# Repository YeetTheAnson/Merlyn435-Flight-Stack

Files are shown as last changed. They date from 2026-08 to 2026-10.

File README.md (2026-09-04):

# Merlyn435 Flight Stack

## Introduction
This is my custom Merlyn435 Flight Stack! This project was made as a successor to my previous Merlyn411 flight controller due to several limitations. It lacked in its processing power and free UART ports. Its mounting pattern was also unconventional at 25mm, making its mounting incompatible with any ESCs on the market. By upgrading to the AT32F435@288MHz, the new Merlyn435 easily handles 8k8 PID loop and advanced autonomous flights with 3 spare UART ports.

The Merlyn435 also upgrades the IMU from the MPU6500 to the LSM6DSK320X, which provides significantly better vibration noise rejection at $3.8\ \mathrm{mdps}/\sqrt{\mathrm{Hz}}$ compared to $10\ \mathrm{mdps}/\sqrt{\mathrm{Hz}}$. This results in cooler motors and more stable flights with fewer gyro filters, preventing issues such as mid throttle oscillation and flyaways.

The Merlyn435 flight controller is designed for a wide battery voltage ranging from 2 to 6 cells. This flight controller can also be mounted in various sizes of drones from 2" to as big as it can get.

It is a 3 in 1 flight controller offers features such as an integrated 2.4GHz ExpressLRS receiver and an OSD to overlay telemetry directly in the video feed. Furthermore, it has 16MB of flash memory for blackbox logging to assist in flight tuning.

The MerlynESC is a 4 in 1 ESC which runs on Bluejay firmware and also operates from 2 to 6s battery voltages. Its maximum continuous current is 40A per motor and peaks up to 55A for a maximum duration of 10 seconds.

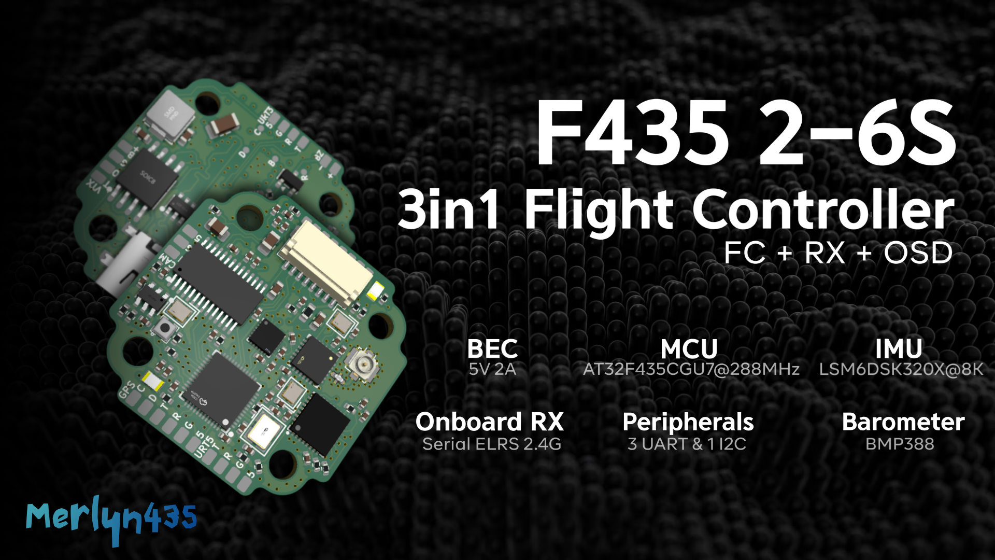
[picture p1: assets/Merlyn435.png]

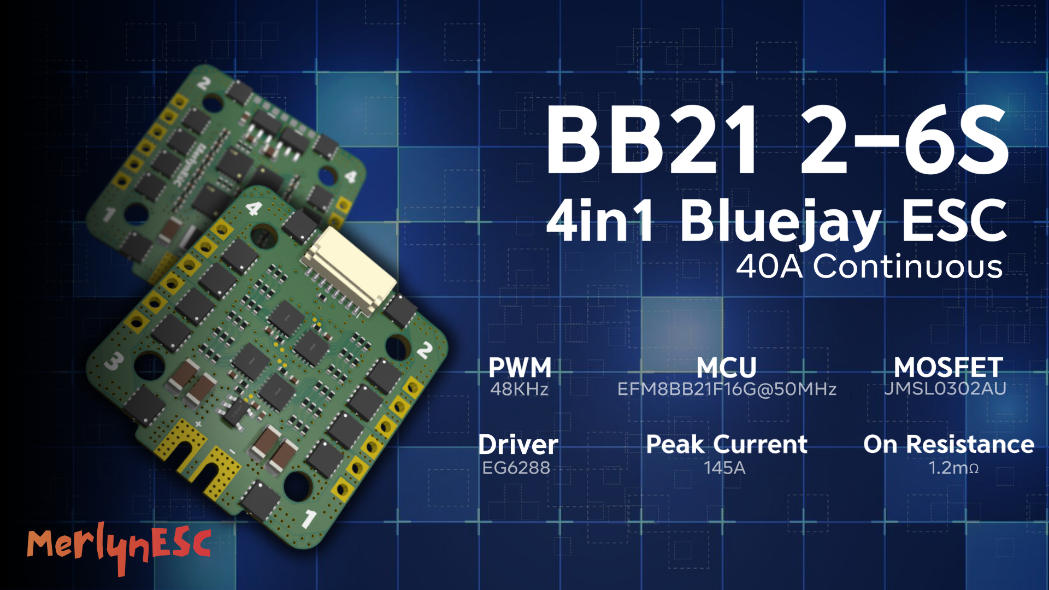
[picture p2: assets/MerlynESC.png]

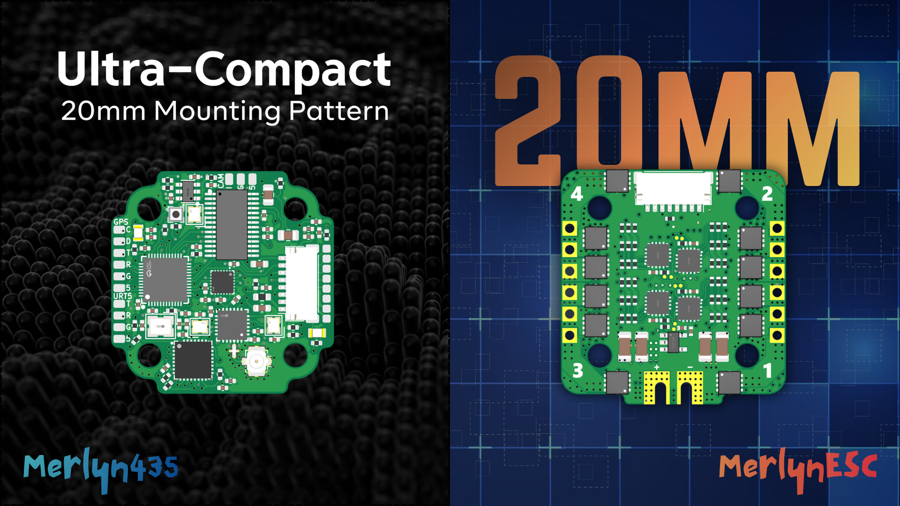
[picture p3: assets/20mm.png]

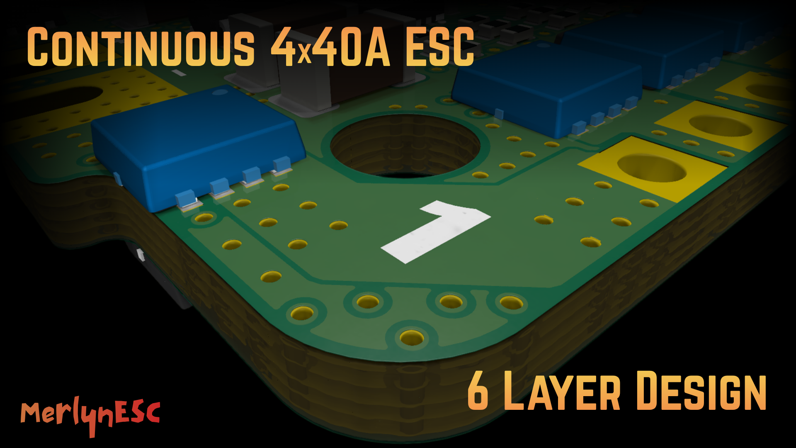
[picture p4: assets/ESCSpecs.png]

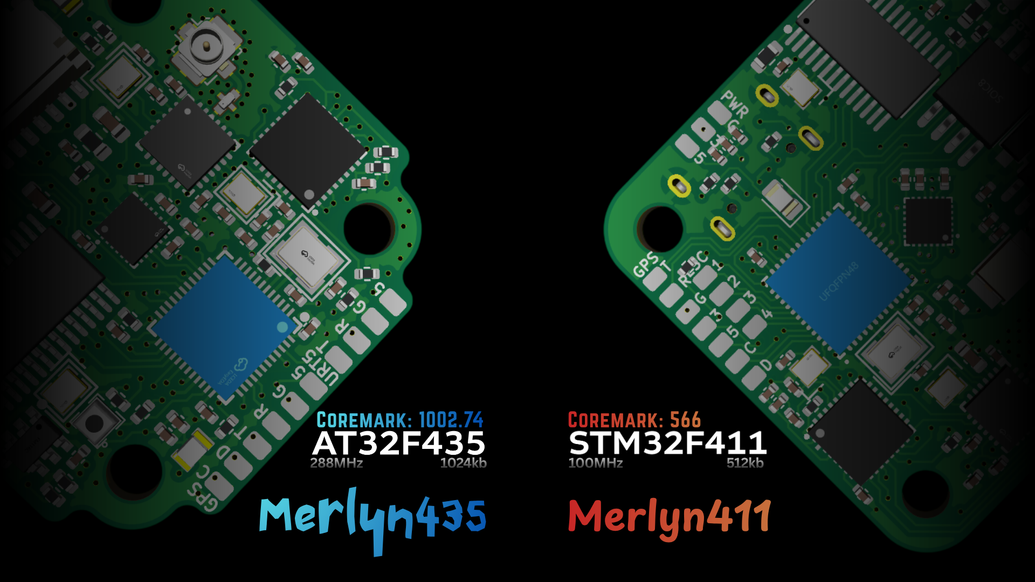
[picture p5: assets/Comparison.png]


| Feature | Merlyn435 | Merlyn411 |
|---|---|---|
| **MCU** | AT32F435CGU7 @ 288MHz | STM32F411CEU6 @ 100MHz |
| **MCU Flash Size** | 1024kB | 512kB |
| **UART Interfaces** | 5 Hardware UART (2 internal, 3 free) | 2 Hardware UART + 1 SoftSerial (1 internal, 1 softserial, 1 free) |
| **IMU** | LSM6DSK320X (SPI) | MPU6500 (SPI) |
| **Barometer** | BMP388 (I2C) | None |
| **OSD** | AT7456E (SPI) | AT7456E (SPI) |
| **Blackbox Flash** | 16MB (SPI) | 16MB (SPI) |
| **Integrated Receiver** | Serial ExpressLRS 2.4GHz  | Serial ExpressLRS 2.4GHz |
| **Mounting Size** | M2 20x20mm | M2 25.5x25.5mm |
| **BEC** | 5V 2A @ 1.1MHz Synchronous | 5V 2A @ 150kHz Asynchronous |
| **ESC Connection** | 8 pin JST-SH (Betaflight standard) | Direct solder pads |

## Hardware Specifications

### Merlyn435
* **MCU:** AT32F435CGU7
* **IMU:** LSM6DSK320X @ SPI1
* **Barometer:** BMP388 @ 0x76
* **OSD:** AT7456E @ SPI2
* **Blackbox:** W25Q128JV 16MB Flash @ SPI2
* **Receiver:** Serial ExpressLRS (ESP8285 + SX1281) @ UART2
* **Voltage range:** 2-6s LiPo / Li-ion / LiHV
* **Power Supply:** LMR51420YDDCR buck converter + SPX3819M5-L-3-3 LDO
* **Mounting:** M2 20x20mm

### MerlynESC
* **MCU:** EFM8BB21F16G
* **MOSFET:** JMSL0302AU
* **Gate Driver:** EG6288
* **Max Current:** 145A Peak / 40A Continuous @ 1.2mΩ
* **Voltage range:** 2-6s LiPo / Li-ion / LiHV
* **Power Supply:** HT75C0-1 12V LDO + HT7533-1 3.3V LDO
* **Mounting:** M2 20x20mm

## Pinout
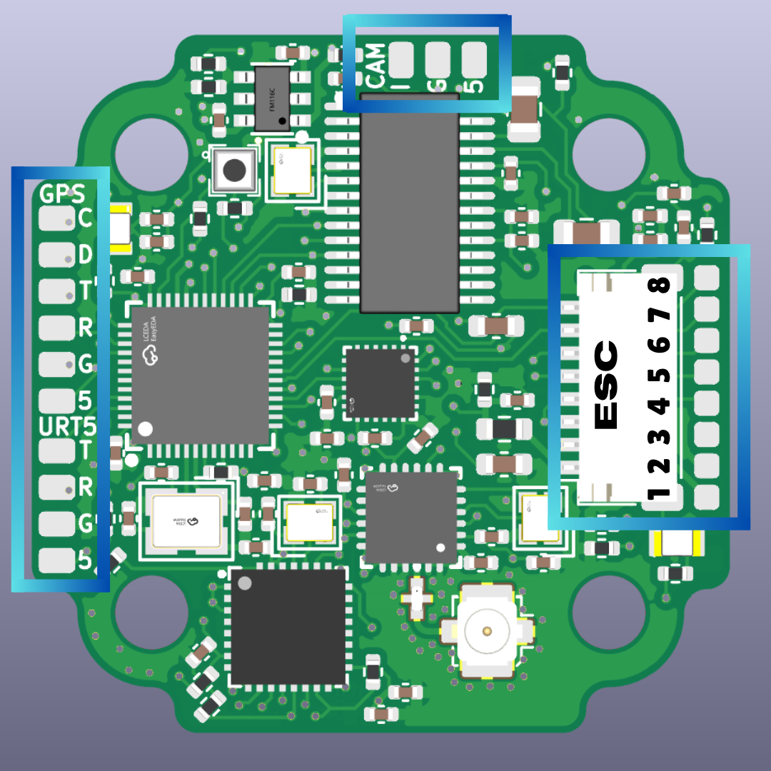
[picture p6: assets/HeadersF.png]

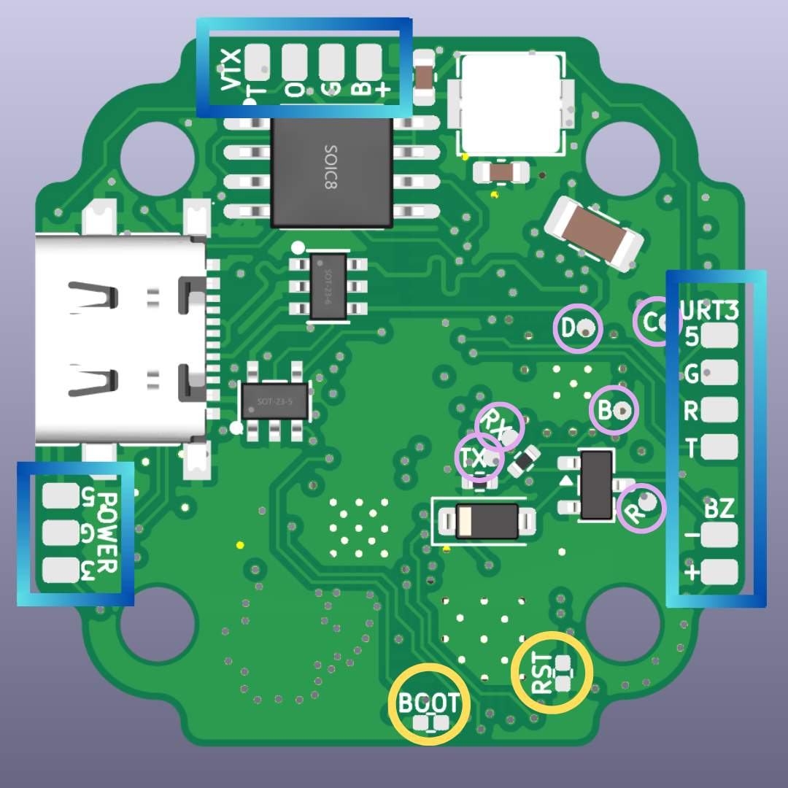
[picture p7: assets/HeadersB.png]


| Header | Pin name | AT32 Pin | Description |
|---|---|---|---|
| **ESC** | `(1)BAT+` | - | Battery Positive Input from ESC |
| | `(2)GND` | - | Ground |
| | `(3)NC` | - | No Connection |
| | `(4)CURR` | PA1 | Current Sense Input |
| | `(5)M1` | PB6 | Motor 1 Signal Output |
| | `(6)M2` | PB7 | Motor 2 Signal Output |
| | `(7)M3` | PB0 | Motor 3 Signal Output |
| | `(8)M4` | PB1 | Motor 4 Signal Output |
| **GPS** | `C` | PH2 | I2C SCL (Internal BMP388 & External Magnetometer) |
| | `D` | PH3 | I2C SDA (Internal BMP388 & External Magnetometer) |
| | `T` | PB4 | UART7 TX |
| | `R` | PB3 | UART7 RX |
| | `G` | - | Ground |
| | `5` | - | 5V Power Output |
| **URT5** | `T` | PB9 | UART5 TX |
| | `R` | PB8 | UART5 RX |
| | `G` | - | Ground |
| | `5` | - | 5V Power Output |
| **CAM** | `I` | - | Analog Video Input |
| | `G` | - | Ground |
| | `5` | - | 5V Power Output |
| **URT3** | `5` | - | 5V Power Output |
| | `G` | - | Ground |
| | `R` | PB11 | UART3 RX |
| | `T` | PB10 | UART3 TX |
| **VTX** | `T` | PA9 | UART1 TX (IRC Tramp / SmartAudio) |
| | `O` | - | Analog Video Output (OSD Overlay) |
| | `G` | - | Ground |
| | `B+` | - | Battery Output for VTX |
| **BZ** | `-` | PC15 | Beeper MOSFET  Pin |
| | `+` | - | 5V Power Output |
| **POWER** | `3` | - | 3.3V Power Input/Output |
| | G | - | Ground |
| | `5` | - | 5V Power Input/Output |
| **Test Points** | `RX` | PA2 | UART2 TX (ExpressLRS RX) |
| | `TX` | PA3 | UART2 RX (ExpressLRS TX) |
| | `D` | PA13 | SWDIO (Debug & Flash) |
| | `C` | PA14 | SWCLK (Debug & Flash) |
| | `R` | NRST | NRST (Debug & Flash) |
| | `B` | BOOT0 | BOOT0 (Debug & Flash) |
| **Jumpers** | `BOOT` | ESP8285 GPIO0 | Bridge to enter ExpressLRS bootloader mode |
| | `RST` | ESP8285 CHIP_EN | Bridge to disable internal ExpressLRS receiver |

----

## Hardware Overview

### Merlyn435
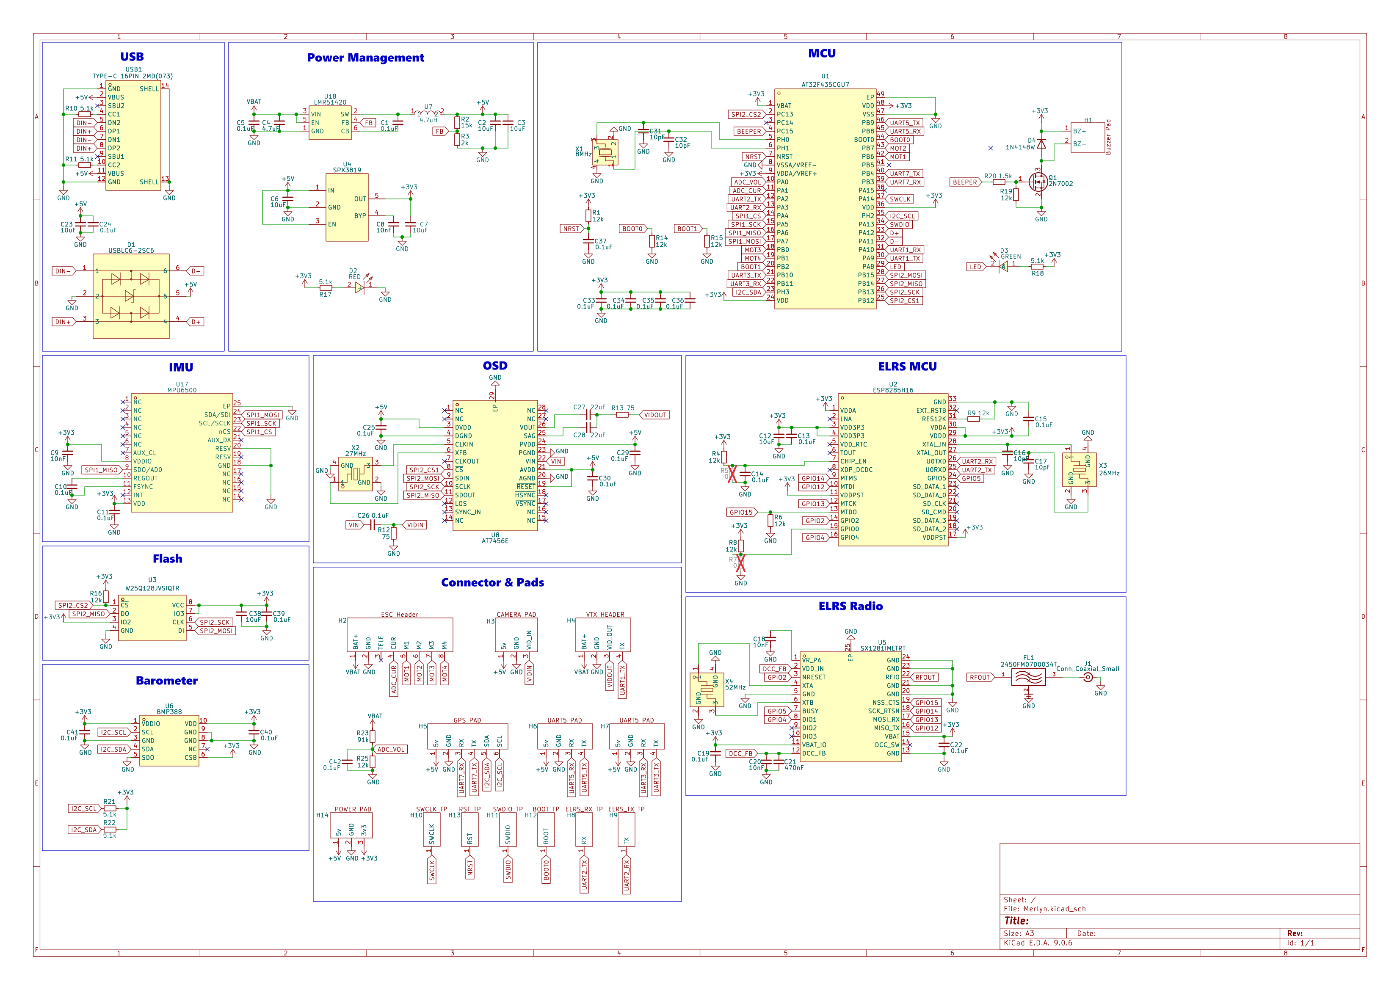
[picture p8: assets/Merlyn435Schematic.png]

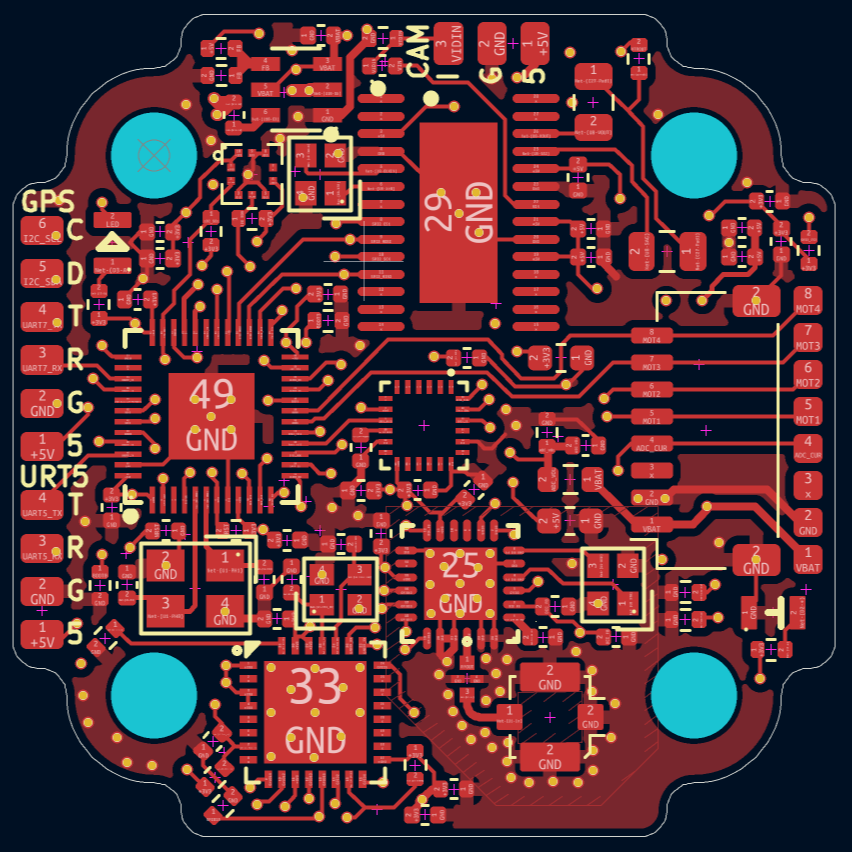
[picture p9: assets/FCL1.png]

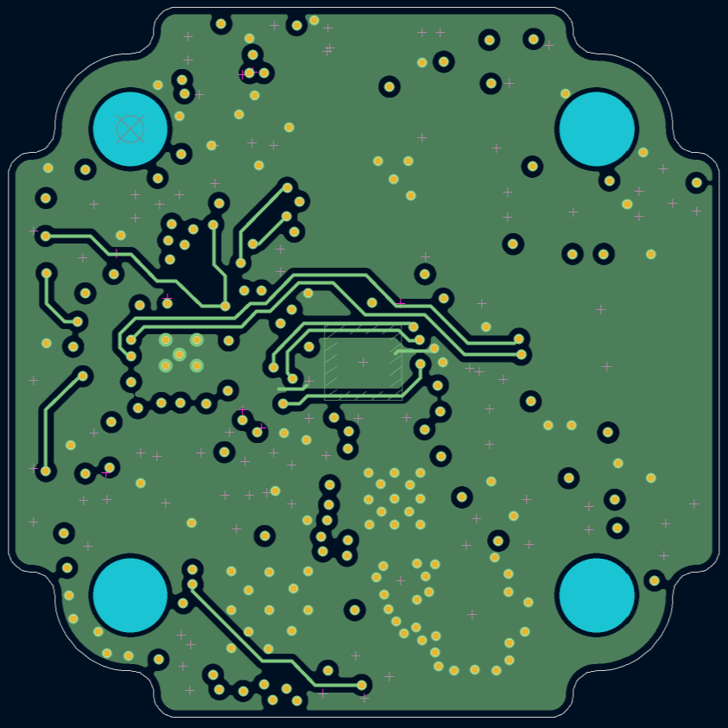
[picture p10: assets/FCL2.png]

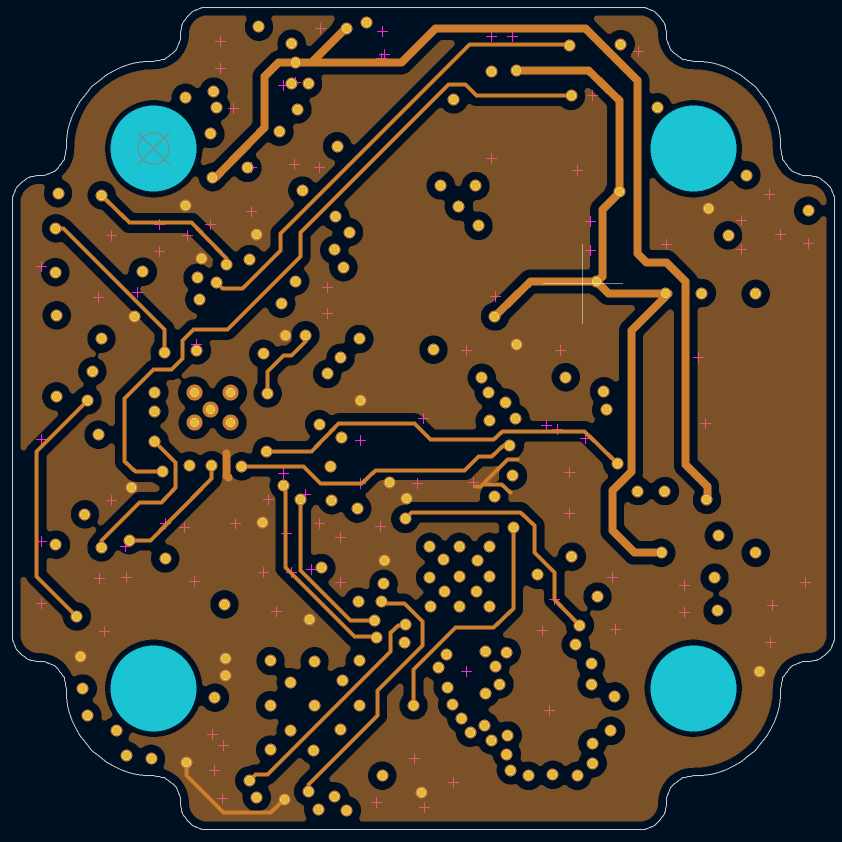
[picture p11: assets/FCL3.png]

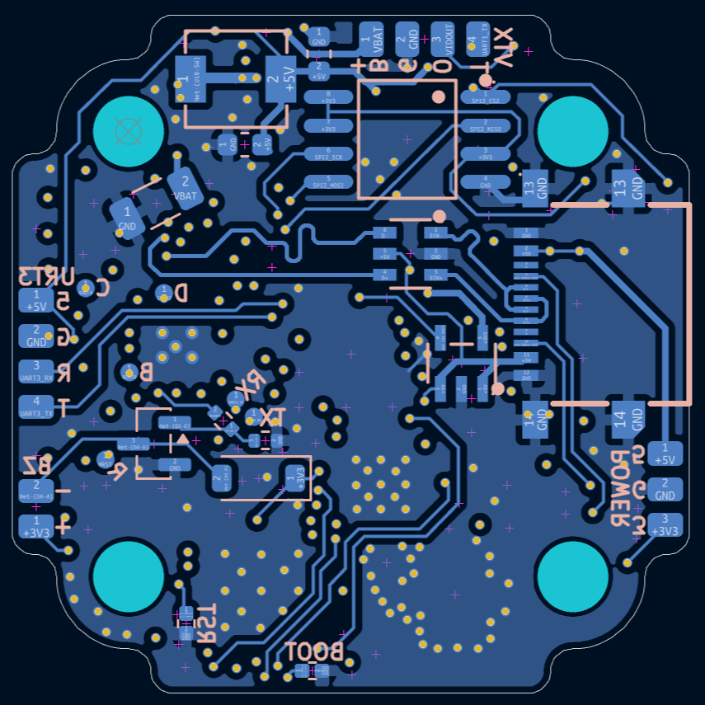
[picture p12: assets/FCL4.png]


### MerlynESC
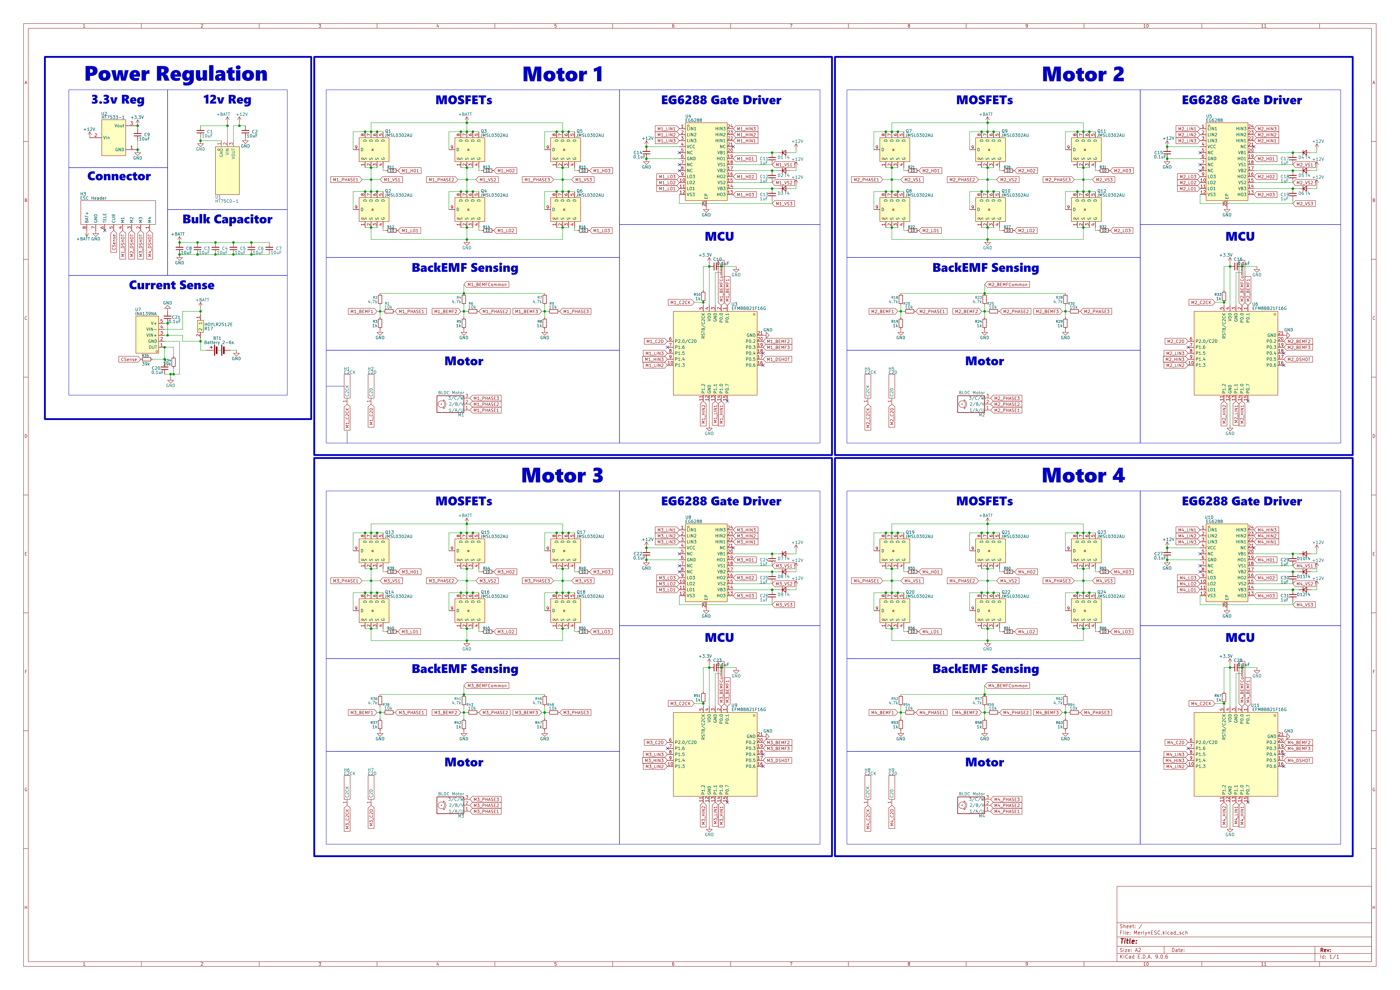
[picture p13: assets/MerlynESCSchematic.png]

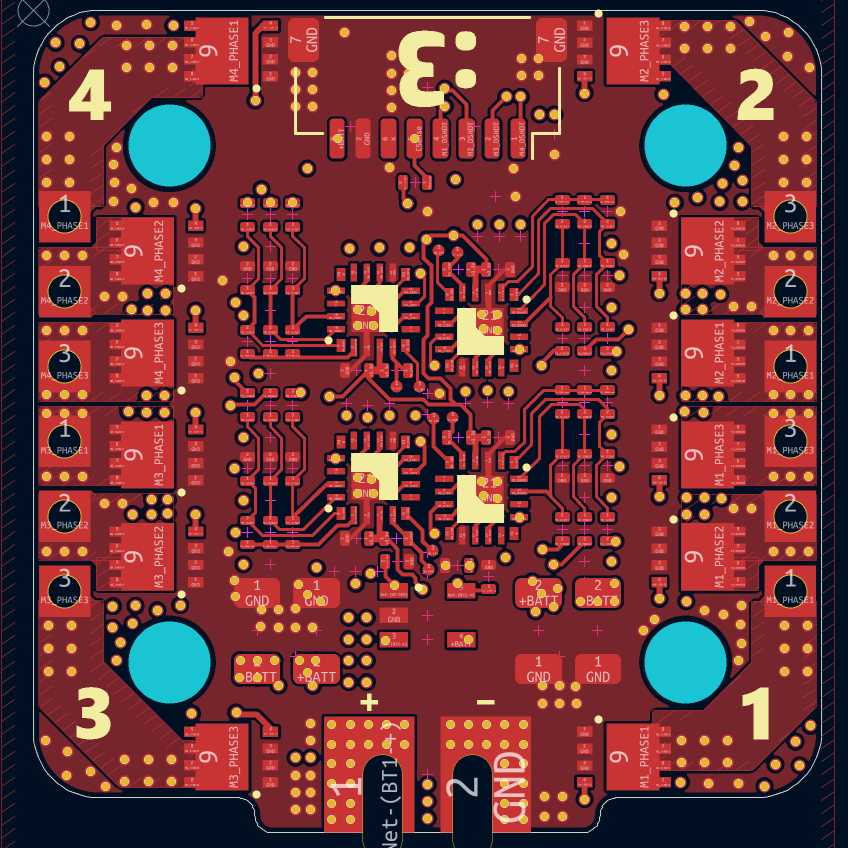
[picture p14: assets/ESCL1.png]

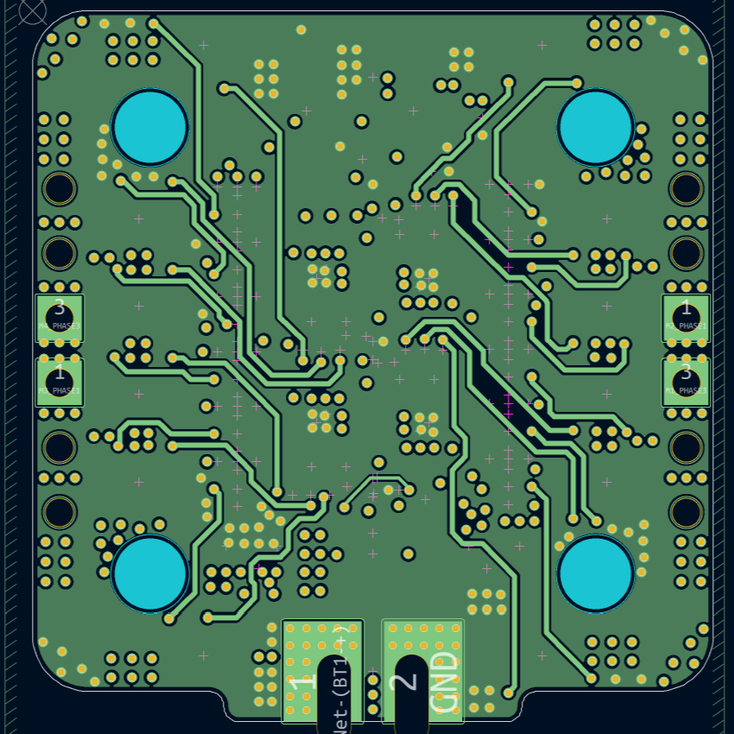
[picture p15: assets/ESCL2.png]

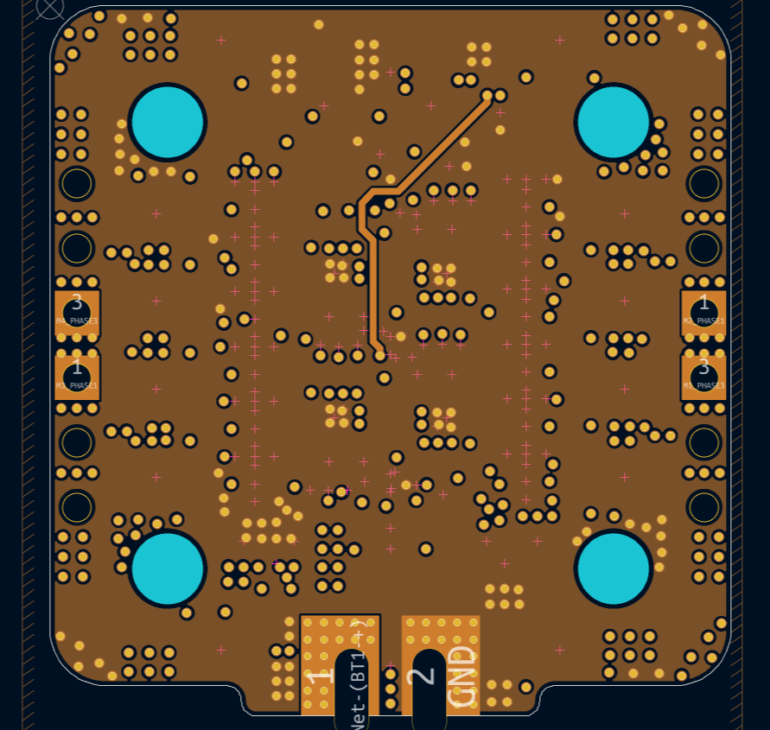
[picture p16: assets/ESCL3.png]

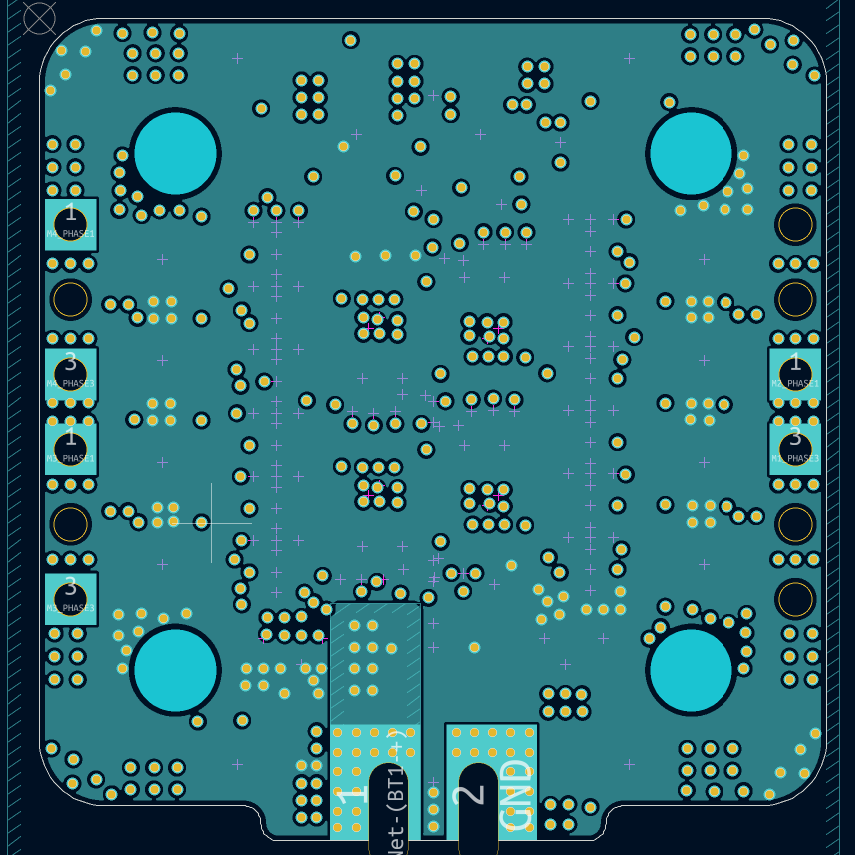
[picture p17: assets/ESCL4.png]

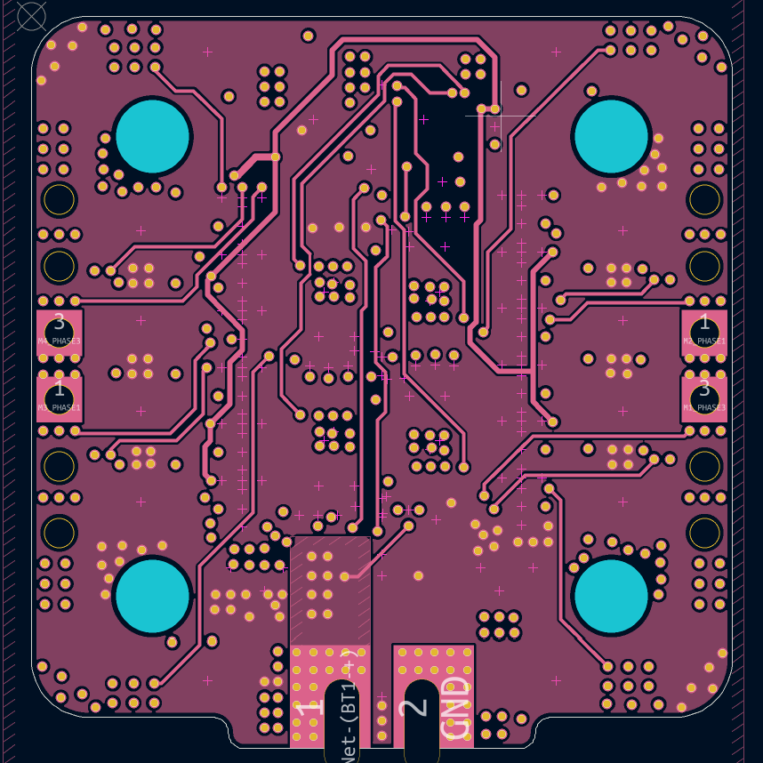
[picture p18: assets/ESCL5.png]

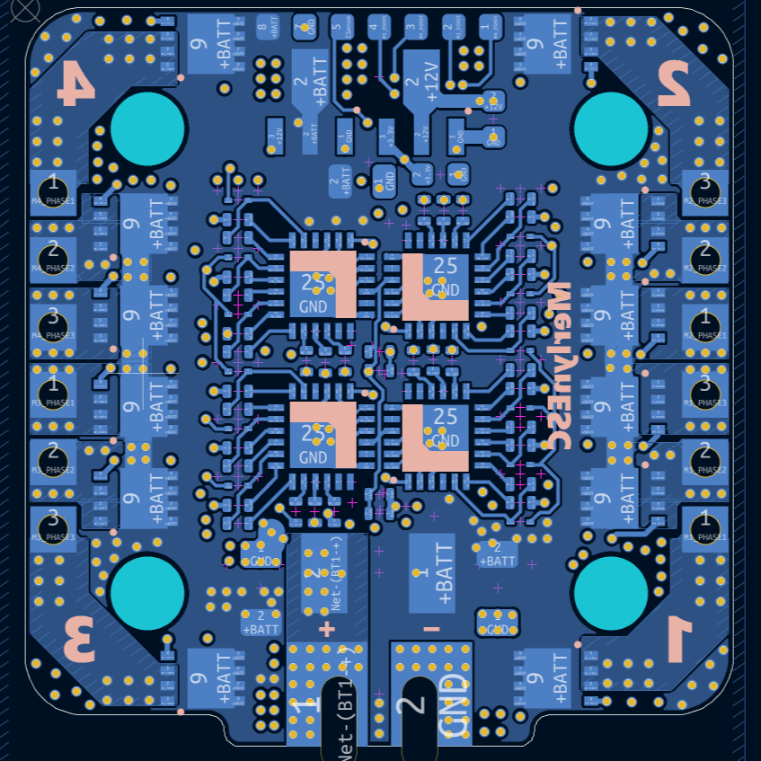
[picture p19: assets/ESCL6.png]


----

## Flight Controller Firmware
Because the Merlyn435 is a custom hardware layout with no existing Betaflight targets, you must compile Betaflight using the custom target definitions in [/firmware/source/betaflight](https://github.com/YeetTheAnson/Merlyn435-Flight-Stack/tree/main/firmware/source/betaflight) or use the pre compiled firmware of your preferred Betaflight version in [/firmware/binaries](https://github.com/YeetTheAnson/Merlyn435-Flight-Stack/tree/main/firmware/binaries)

> [!IMPORTANT]
> The LSM6DSK320X was officially added in **v2026.6**. The same **Betaflight** configuration can be used to compile your binary for both **2025.12** and **2026.6** without any issues. However, **2025.12 does not support or detect the LSM6DSK320X**, so the **LSM6DSK320X** IMU will only function when running **2026.6 or later**.

### How to build the firmware (Betaflight)
1. Clone the [betaflight repository](https://github.com/betaflight/betaflight) using any UNIX terminal (use MSYS2 MINGW64 on Windows) and enter the directory
2. Enter `make configs` (install any required GCC toolchain if asked)
3. Create a directory in betaflight/src/config/configs named `MERLYN435` and paste [config.h](https://github.com/YeetTheAnson/Merlyn435-Flight-Stack/tree/main/firmware/source/betaflight/config.h) in the new directory
  - For v2026.6 and later, create a directory in configs named "ANSN" before creating the `MERLYN435` directory inside "ANSN"
4. Enter `make MERLYN435` and the `.hex` file should appear in `betaflight/obj`

### How to build the firmware (iNav)
1. Clone the [iNav repository](https://github.com/iNavFlight/inav) using any UNIX terminal (Building iNav is not supported on Windows) and enter the directory
2. Switch to the latest iNav stable release. E.g. `git checkout 9.1.0`
3. Create two directories. One named `build` in the root directory and another named `MERLYN435` in /src/main/target
4. Copy `CMakeLists.txt`, `target.c` and `target.h` into the `MERLYN435` directory from [/firmware/source/inav](https://github.com/YeetTheAnson/Merlyn435-Flight-Stack/tree/main/firmware/source/inav)
5. Enter the `build` directory
6. Enter `cmake ..` (install any required GCC toolchain if asked)
7. Enter `make MERLYN435` and the `.hex` file should appear in `/build`

### Flight Controller Flashing
1. **Via USB DFU Mode (Recommended):** Short the SWD `B` test point to 3.3v and plug in the USB C cable. Open [Betaflight Configurator](https://app.betaflight.com) (applicable for iNav), select your compiled local `.hex` file, and click Flash Firmware.
2. **Via SWD:** If the bootloader is corrupted, connect an ST Link programmer to the `B`, `D` and `C` test points (`R` is optional) and flash the compiled binary with STM32CubeProgrammer.

## ExpressLRS Flashing
The internal ESP8285 ExpressLRS receiver is wired to the AT32 via UART2. It uses the **BETAFPV 2.4GHz Lite RX** firmware target. The firmware binaries can be obtained from the ELRS [site](https://expresslrs.github.io/web-flasher/) or from this repository in [/firmware/binaries](https://github.com/YeetTheAnson/Merlyn435-Flight-Stack/blob/main/firmware/binaries/(ExpressLRS)MERLYN435_v4.10_FCC.bin). There are two way to flash the receiver:

### Method 1: Betaflight Passthrough
Note that Betaflight must be installed and configured before passthrough works.
1. Bridge the BOOT pad
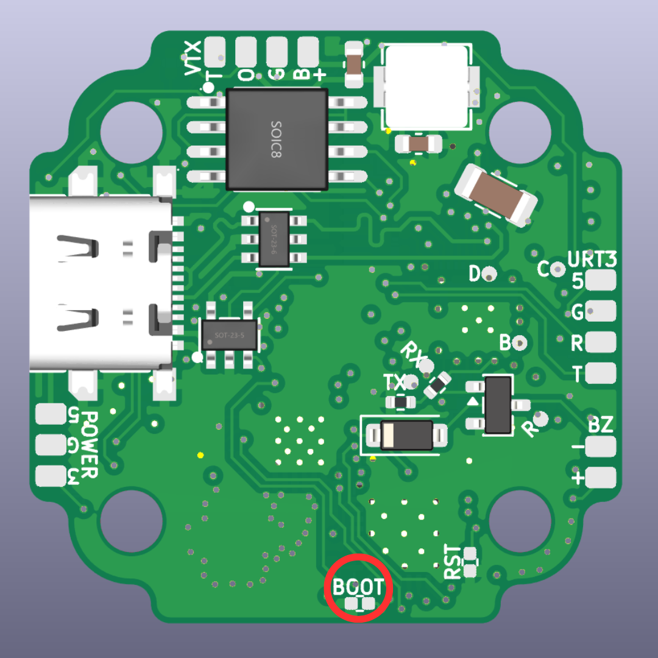
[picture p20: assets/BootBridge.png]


2. Connect the FC via USB
3. Open the ExpressLRS Configurator [web flasher](https://expresslrs.github.io/web-flasher/) or app
4. Select `Receiver`
5. Select your preferred firmware version and the `BETAFPV 2.4GHz Lite RX` target and press next
6. [OPTIONAL] Enter your bind phrase
7. Select the Betaflight Passthrough flashing method, press next and follow the steps

### Method 2: Manual Flashing
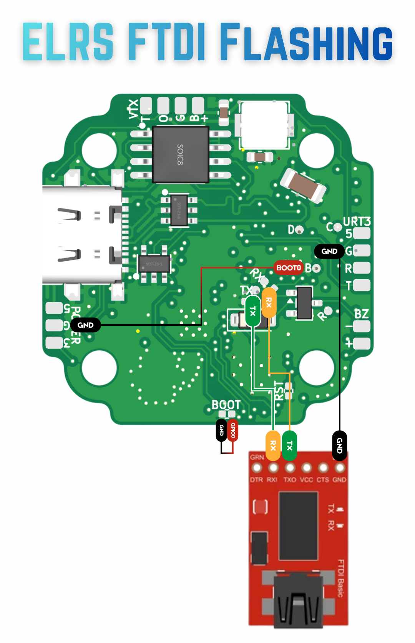
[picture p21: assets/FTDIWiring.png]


If the ESP8285 is bricked or passthrough fails, you can flash it directly using an FTDI adapter or another ESP8285/ESP8286/ESP32 or even an Arduino. Bridge `R` to `GND` as well as the BOOT jumper and connect the FTDI TX to RX and FTDI RX to TX

## ESC Flashing
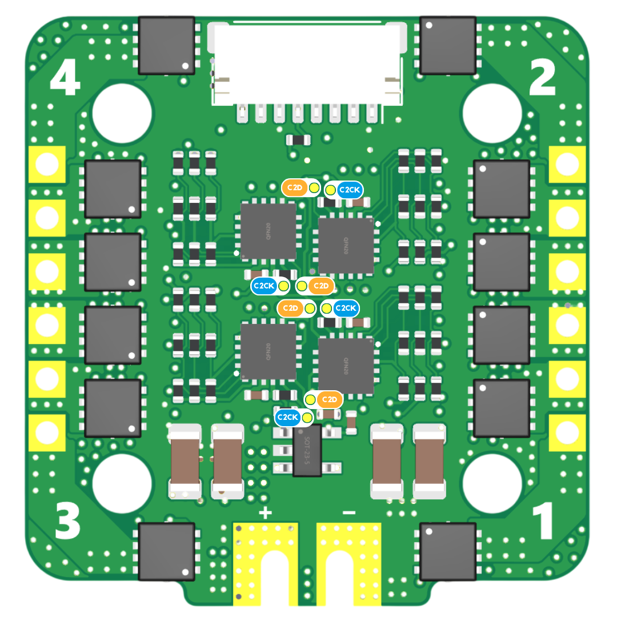
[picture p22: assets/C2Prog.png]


The MerlynESC is a 4 in 1 ESC that runs Bluejay firmware target `A`, MCU type `H`, `30`x20.4ns deadtime and `48`KHz PWM frequency. The firmware files can be found in [/firmware/binaries](https://github.com/YeetTheAnson/Merlyn435-Flight-Stack/blob/main/firmware/binaries/(Bluejay)A_H_30_48_v0.21.0.hex) or the official Bluejay repository. You can flash the EFM8BB21 chips using the C2 programming pads with a makeshift arduino programmer.

-----

## Drone Assembly

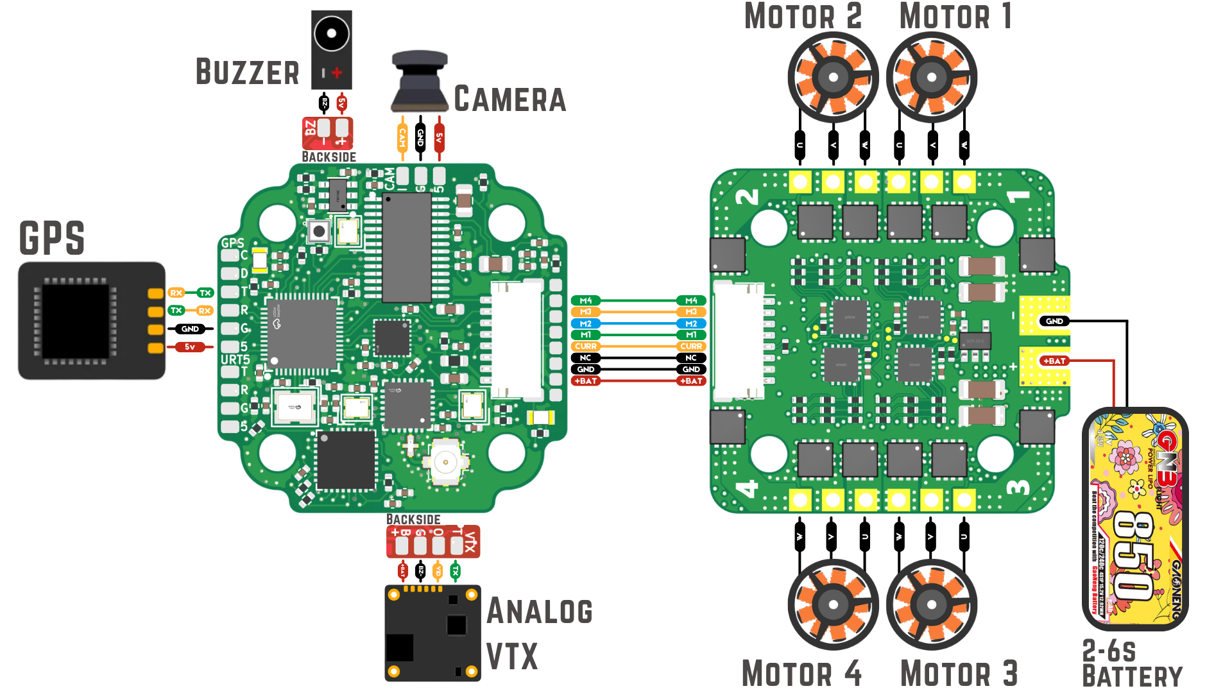
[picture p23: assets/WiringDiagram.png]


While this project is mainly focused on the Merlyn435 + MerlynESC flight stack, I also designed a high performance 3 inch freestyle FPV drone. If you want to recreate the full build, below is the component breakdown:

### Component List
* **Frame:** RATE S30 Pro carbon fiber frame
* **Motors:** RATE 1505 4300KV
* **Propellers:** HQProp 3x3x3
* **Camera:** Caddx Ratel 2 analog camera
* **VTX:** Cyclone 1W analog video transmitter
* **GPS:** RATE M10 GPS module
* **Battery:** GNB 4S 850mAh 120C LiHV
* **Fasteners (If using CF frame):** Included with frame kit
* **Fasteners (If using 3d printed frame):**
  * 6x M3 20mm Female to Female Brass Standoffs 
  * 12x M3 6mm Screws
  * 4x M2 Nuts
  * 4x M2 20mm Screws
  * 8x M2 10mm Screws
  * 16x M2 6mm Screws
  * 4x M2 6mm Screws
  * 8x M2 6mm Self Tapping Screws

### Why 3D Printing the Frame is Not Recommended
I advise against 3D printing your frame. On my previous build, a 100 percent infill PETG frame shattered from a very light fall. More importantly, 3D printed frames flex and resonate which causes excessive gyro noise and leads to deteriorated flight performance. 

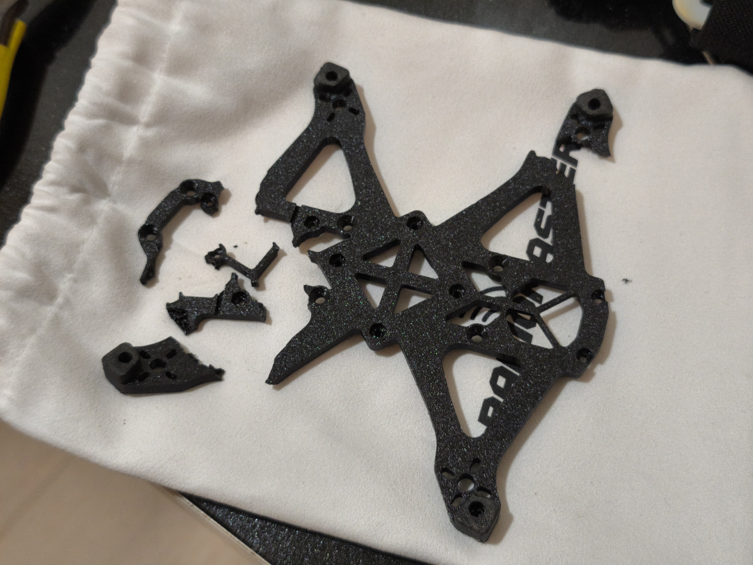
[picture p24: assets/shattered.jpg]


https://github.com/user-attachments/assets/90db9ad2-082e-437a-b4b3-71ebe933a74a

### Assembly Instructions
The Merlyn435 and ESC uses standard 20x20mm mounting hole distance.

#### Stack Mounting
1. Place 4x M2 Nuts into the recesses in the bottom frame plate.

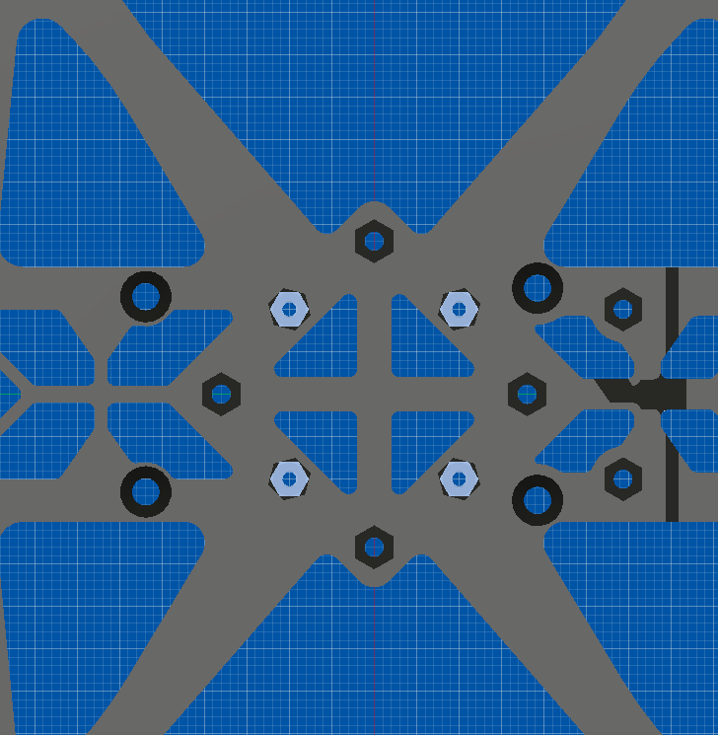
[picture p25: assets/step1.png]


2. Push rubber grommets into the flight controller and ESC mounting holes.

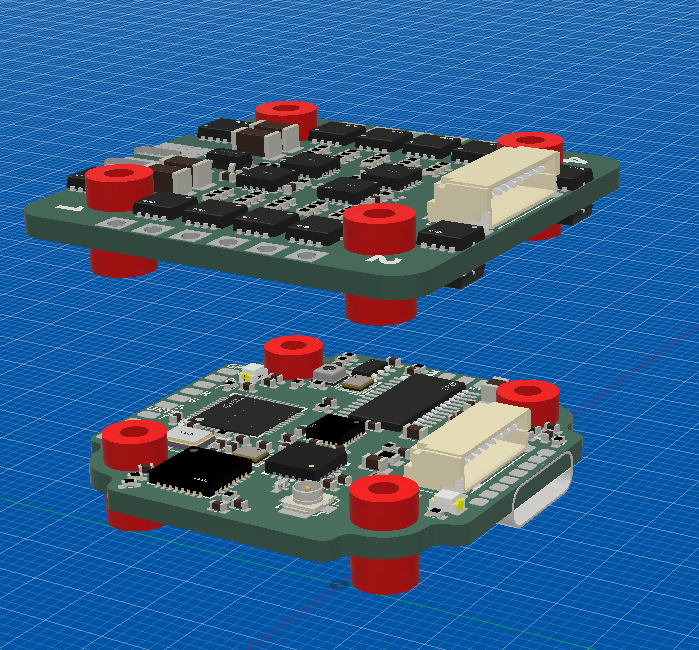
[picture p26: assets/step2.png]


3. Push 4x M2 20mm screws through the adapter plate, through the rubber grommet, and through 
the bottom plate into the M2 nuts.

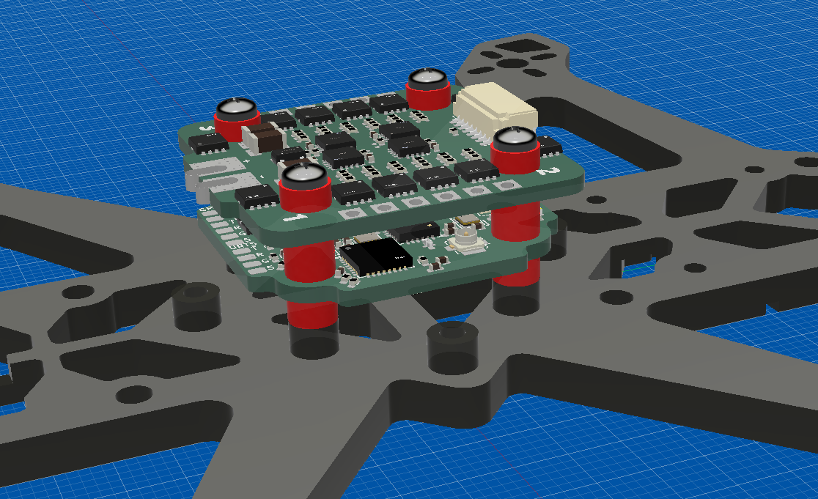
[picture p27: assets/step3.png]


#### VTX Mounting
The VTX mounts to the rear of the frame.
1. Place 4x M2 Nuts into the recesses in the bottom frame plate.

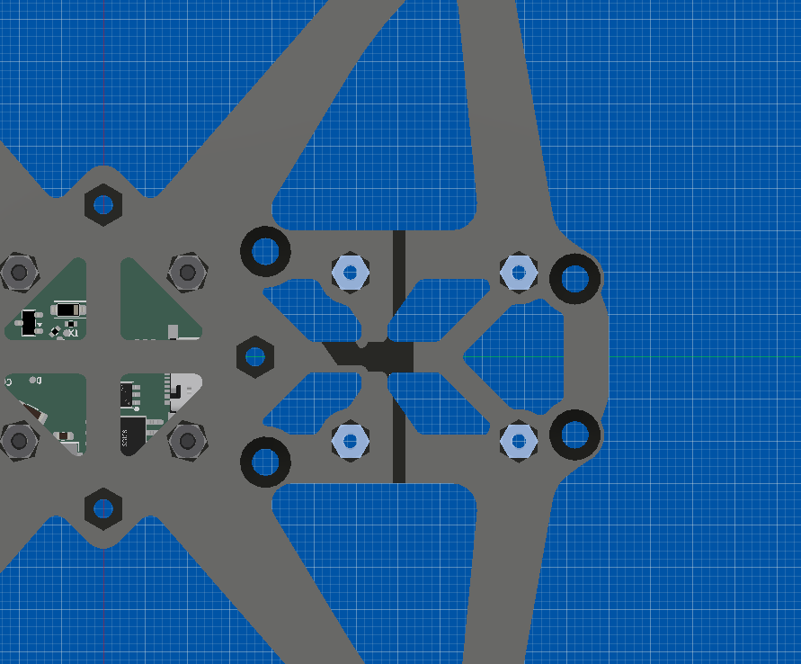
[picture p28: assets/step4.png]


2. Push rubber grommets into the VTX mounting holes.

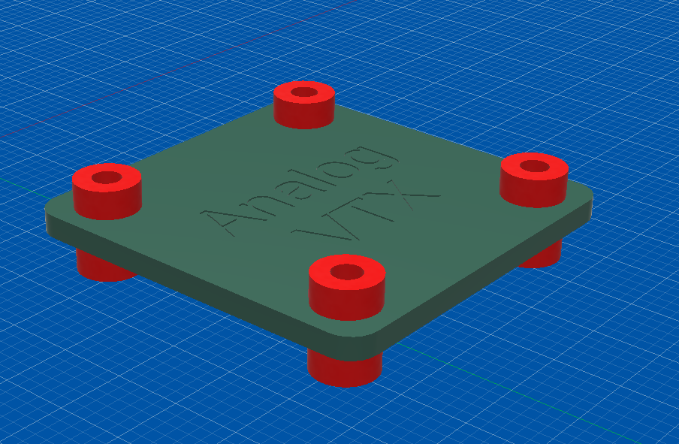
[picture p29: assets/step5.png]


3. Push 4x M2 10mm screws through rubber grommets, down through the bottom plate, and into the M2 nuts.

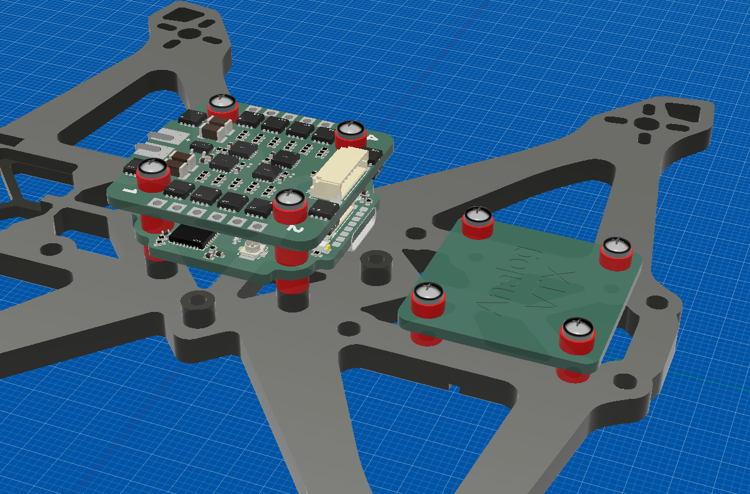
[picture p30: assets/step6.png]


#### Motor Mounting
1. Mount the four 1505 4300KV motors to the arms using 16x M2 6mm screws (4 per motor). Ensure the screws do not touch the motor windings inside the bell.

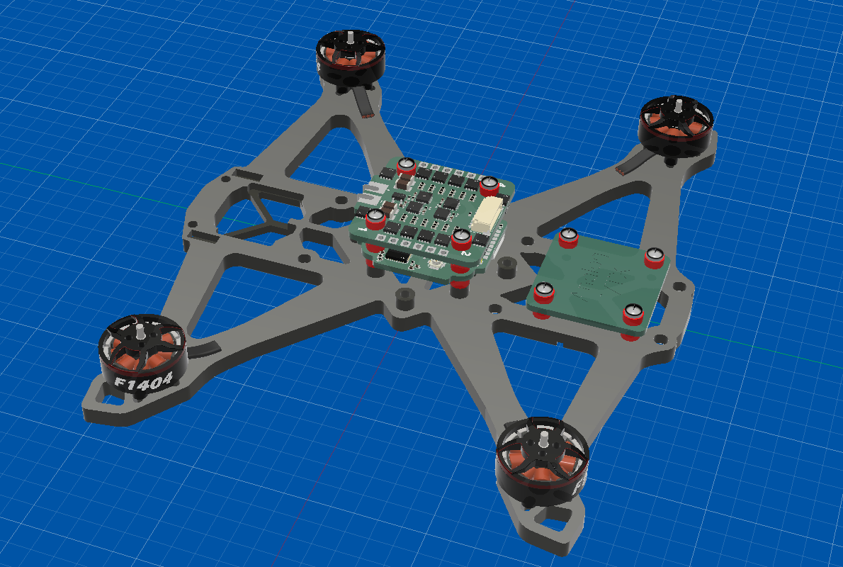
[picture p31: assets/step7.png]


2. Mount the HQPROP 3x3x3 propellers. Pay attention to motor rotation directions (depending on your betaflight configuration, it could either be prop in or prop out). Fasten each prop with 2x M2 6mm screws.

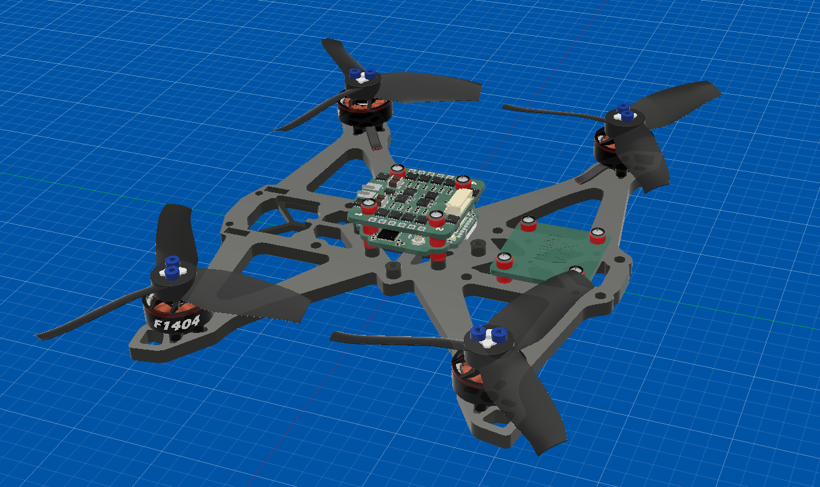
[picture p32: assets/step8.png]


#### Remaining Components
1. Mount the analog FPV camera to the cage using 2x M2 6mm screws.

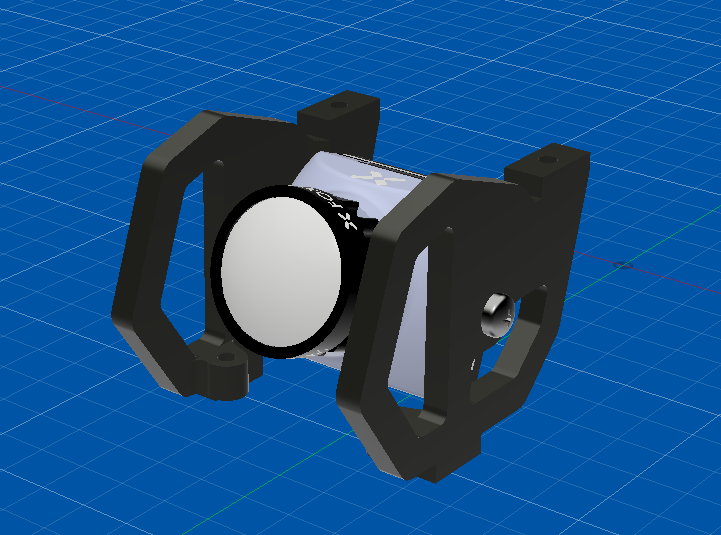
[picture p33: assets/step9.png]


2. Mount the camera cage to the bottom frame using 2x M2 6mm Self Tapping screws.

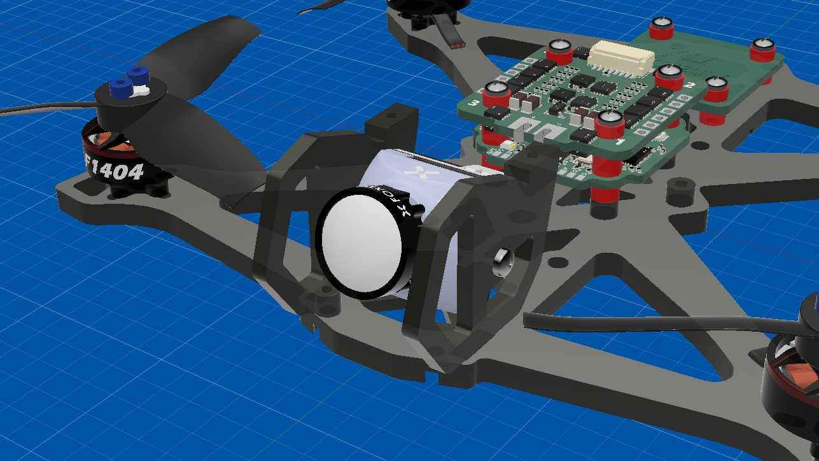
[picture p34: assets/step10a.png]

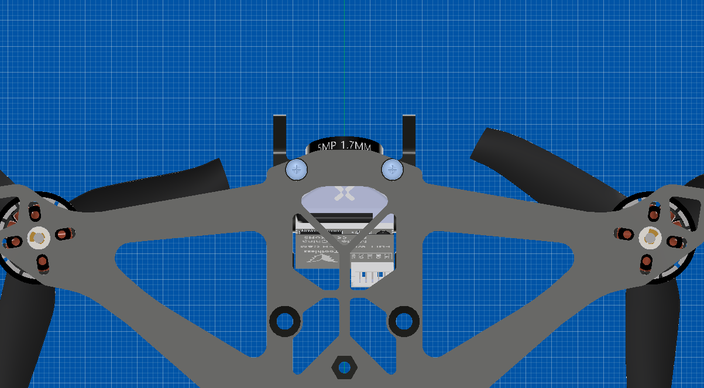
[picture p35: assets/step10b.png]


3. Mount the 6x M3 20mm Female to Female Brass Standoffs and secure with 6x M3 6mm screws to the bottom plate.

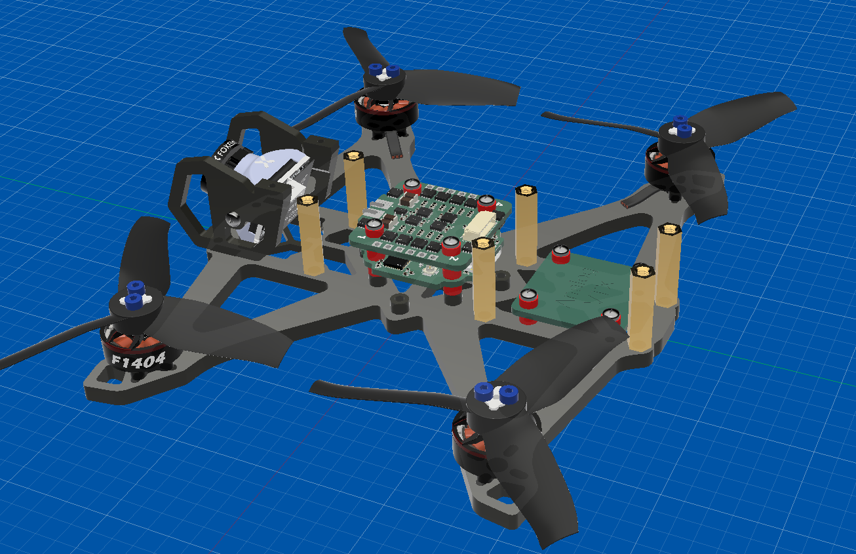
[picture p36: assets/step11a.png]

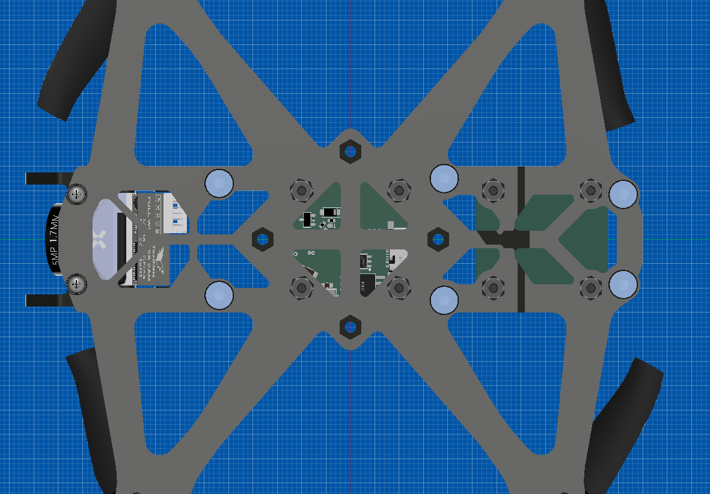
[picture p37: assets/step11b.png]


4. Press fit the antenna holder to the brass standoffs, then insert the antenna and connect the antenna to the VTX.

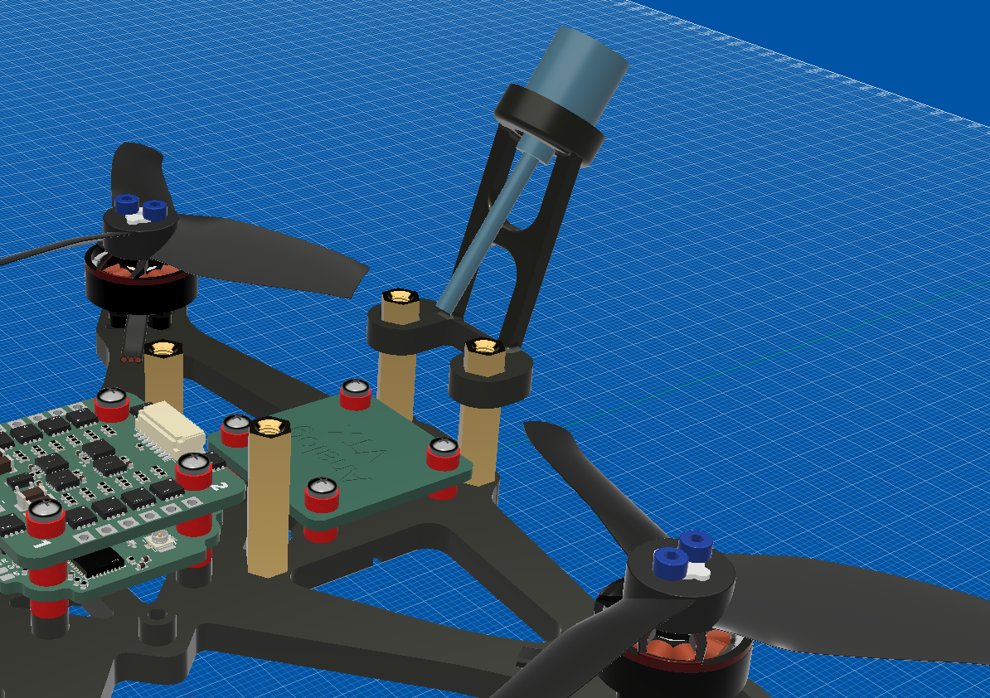
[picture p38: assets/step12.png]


5. Press fit the GPS module into the bracket.

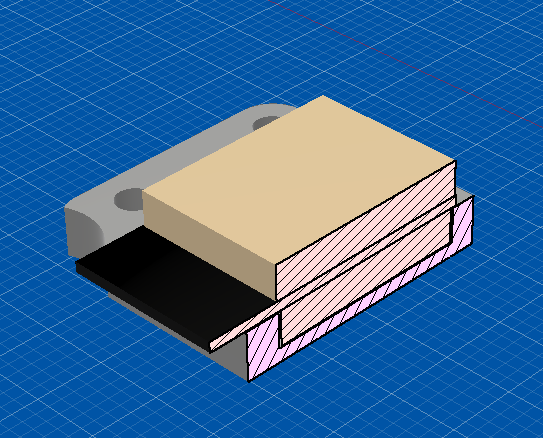
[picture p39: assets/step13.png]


6. Mount the top plate and secure with 6x M3 6mm screws.

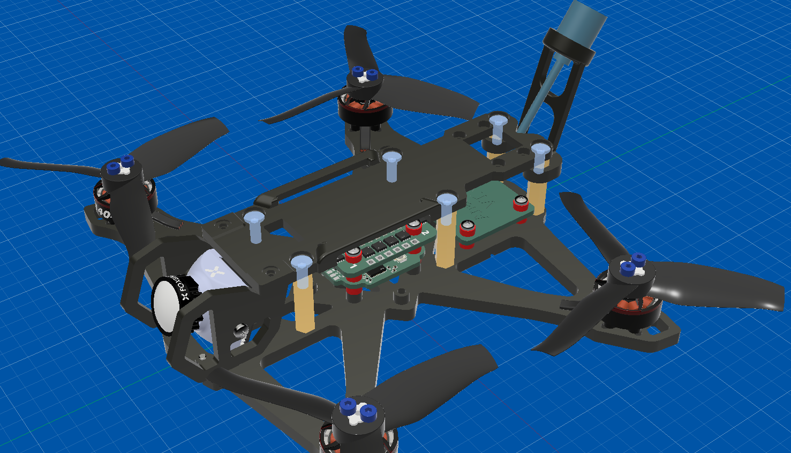
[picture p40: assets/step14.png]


7. Mount the GPS module and bracket underneath the top plate and secure with 4x M2 6mm Self Tapping screws.



8. Insert 2x M2 6mm Self Tapping screws to secure the top plate to the camera cage.



----

## Bill of Material

Note: The prices in USD are converted as of 22 August 2026 and may fluctuate. Promo codes will be applied before checkout to bring the costs down. And yes, the costs of separate components are cheaper than JLCPCB assembly.

| Category | Item Name | Description | Link | Vendor | Quantity | Total Price (USD) |
|---|---|---|---|---|---:|---:|
| Flight Controller | TAXM8M4RDBCCT2T | 8 MHz crystal | [link](https://www.lcsc.com/product-detail/C400090.html) | LCSC | 5 | 0.73 |
| Flight Controller | 7D027000I01 | 27 MHz crystal | [link](https://www.lcsc.com/product-detail/C648952.html) | LCSC | 5 | 0.50 |
| Flight Controller | XL7EL89CMI-111YLC-26M | 26 MHz crystal | [link](https://www.lcsc.com/product-detail/C19272774.html) | LCSC | 5 | 0.44 |
| Flight Controller | XC21M4-52.000-F10NNHPL | 52 MHz crystal | [link](https://www.lcsc.com/product-detail/C3034316.html) | LCSC | 5 | 0.68 |
| Flight Controller | TYPE-C 16P QTWT | USB C Connector SMT | [link](https://www.lcsc.com/product-detail/C5187472.html) | LCSC | 10 | 0.75 |
| Flight Controller | LMR51420YDDCR | Buck converter | [link](https://www.lcsc.com/product-detail/C5383002.html) | LCSC | 2 | 1.96 |
| Flight Controller | AT7456E | Video overlay OSD | [link](https://www.lcsc.com/product-detail/C82351.html) | LCSC | 2 (Two because there's a deal on LCSC that lets me get both for free) | 7.49 |
| Flight Controller | SPX3819M5-L-3-3/TR | 3.3v LDO regulator | [link](https://www.lcsc.com/product-detail/C9055.html) | LCSC | 10 | 2.19 |
| Flight Controller | APH0420T4R7M | 4.7uH inductor | [link](https://www.lcsc.com/product-detail/C5349668.html) | LCSC | 5 | 0.45 |
| Flight Controller | USBLC6-2SC6 | USB ESD protection | [link](https://www.lcsc.com/product-detail/C7519.html) | LCSC | 5 | 0.92 |
| Flight Controller | BWU.FL-IPEX1 | U.FL connector | [link](https://www.lcsc.com/product-detail/C5137195.html) | LCSC | 10 | 0.42 |
| Flight Controller | 0402WGF1202TCE | 12k 0402 resistor | [link](https://www.lcsc.com/product-detail/C25752.html) | LCSC | 100 | 0.69 |
| Flight Controller | 0402WGF1501TCE | 1.5k 0402 resistor | [link](https://www.lcsc.com/product-detail/C25867.html) | LCSC | 100 | 0.50 |
| Flight Controller+ESC | CL10A106MA8NRNC | 10uF 0603 capacitor | [link](https://www.lcsc.com/product-detail/C96446.html) | LCSC | 20 | 1.60 |
| Flight Controller | 1206B475K500NT | 4.7uF 1206 capacitor | [link](https://www.lcsc.com/product-detail/C29823.html) | LCSC | 10 | 2.72 |
| Flight Controller | W25Q128JVSIQ | 16MB flash chip | [link](https://www.lcsc.com/product-detail/C97521.html) | LCSC | 1 | 2.62 |
| Flight Controller | HC-1.0-8PWT | JST SH 8p connector | [link](https://www.lcsc.com/product-detail/C2845367.html) | LCSC | 5 | 0.67 |
| Flight Controller | LSM6DSK320XTR | LSM6 series IMU | [link](https://www.lcsc.com/product-detail/C53025794.html) | LCSC | 1 | 9.18 |
| Flight Controller | PCB | PCB | - | JLCPCB | 1 | 7.00 |
| Flight Controller | Partial PCB Assembly | Partial PCB Assembly | - | JLCPCB | 1 | 47.91 |
| ESC | GRM21BR61H106KE43L | 10uF 0805 capacitor | [link](https://www.lcsc.com/product-detail/C440198.html) | LCSC | 5 | 1.25 |
| ESC | CL31A106KBHNNNE | 10uF 1206 capacitor | [link](https://www.lcsc.com/product-detail/C13585.html) | LCSC | 20 | 5.63 |
| ESC | CL05B104KB54PNC | 0.1uF 0402 capacitor | [link](https://www.lcsc.com/product-detail/C307331.html) | LCSC | 100 | 0.93 |
| ESC | CL05A105KA5NQNC | 1uF 0402 capacitor | [link](https://www.lcsc.com/product-detail/C52923.html) | LCSC | 50 | 0.61 |
| ESC | 1SS400CMT2R | SOD923 diode | [link](https://www.lcsc.com/product-detail/C510311.html) | LCSC | 40 | 1.02 |
| ESC | JMSL0302AU | N channel MOSFET | [link](https://www.lcsc.com/product-detail/C2890409.html) | LCSC | 25 | 7.07 |
| ESC | 0402WGF1002TCE | 10k 0402 resistor | [link](https://www.lcsc.com/product-detail/C25744.html) | LCSC | 100 | 0.19 |
| ESC | 0402WGF4701TCE | 4.7k 0402 resistor | [link](https://www.lcsc.com/product-detail/C25900.html) | LCSC | 100 | 0.50 |
| ESC | 0402WGF1001TCE | 1k 0402 resistor | [link](https://www.lcsc.com/product-detail/C11702.html) | LCSC | 100 | 0.67 |
| ESC | 0402WGF100JTCE | 10R 0402 resistor | [link](https://www.lcsc.com/product-detail/C25077.html) | LCSC | 100 | 0.58 |
| ESC | HoYLR2512E-3W-0.5mR-1% | 0.5mR 2512 shunt resistor | [link](https://www.lcsc.com/product-detail/C5375456.html) | LCSC | 10 | 0.60 |
| ESC | 0402WGF3902TCE | 39k 0402 resistor | [link](https://www.lcsc.com/product-detail/C25783.html) | LCSC | 100 | 0.69 |
| ESC | HT75C0-1 | 12v LDO regulator | [link](https://www.lcsc.com/product-detail/C64551.html) | LCSC | 5 | 0.99 |
| ESC | HT7533-1 | 3.3v LDO regulator | [link](https://www.lcsc.com/product-detail/C14289.html) | LCSC | 5 | 0.71 |
| ESC | EFM8BB21F16G-C-QFN20R | ESC MCU | [link](https://www.lcsc.com/product-detail/C80713.html) | LCSC | 5 | 6.33 |
| ESC | EG6288 | Gate driver | [link](https://www.lcsc.com/product-detail/C55058511.html) | LCSC | 10 | 3.06 |
| ESC | INA139NA/3K | Current sensor | [link](https://www.lcsc.com/product-detail/C129947.html) | LCSC | 2 | 1.12 |
| ESC | PCB | PCB | - | JLCPCB | 1 | 2.00 |
| Flight Controller + ESC | Shipping | EPOST shipping | - | JLCPCB | 1 | 6.49 |
| Flight Controller + ESC | Shipping | LCSC | - | LCSC | 1 | 4.92 |
| Drone Parts | RATE 1505 4300kv motor | Motors | [link](https://click.world.taobao.com/_b.RcEIyQ) | TaoBao | 4 | 28.75 |
| Drone Parts | RATE S30 Pro frame | Carbon fiber frame | [link](https://click.world.taobao.com/_b.6cEImS) | TaoBao | 1 | 23.06 |
| Drone Parts | RATE analog antenna | Right hand circular polarized 5.8GHz antenna | [link](https://click.world.taobao.com/_b.ecEImU) | TaoBao | 1 | 5.80 |
| Drone Parts | RATE 90mm ELRS antenna | Linear polarized dipole 2.4GHz antenna | [link](https://click.world.taobao.com/_b.3cEIO4) | TaoBao | 1 | 0.95 |
| Drone Parts | RATE beeper/buzzer | Active piezo buzzer | [link](https://click.world.taobao.com/_b.VcEIzD) | TaoBao | 1 | 0.64 |
| Drone Parts | HQPROP T3x3x3 | 2 Pairs 3 inch propeller | [link](https://click.world.taobao.com/_b.0cEJ5z) | TaoBao | 1 | 1.88 |
| Drone Parts | RATE XT30 + Cable | Connector and cable | [link](https://click.world.taobao.com/_b.acEJqe) | TaoBao | 1 | 0.64 |
| Drone Parts | RATE Rubber Grommets | 10pcs soft mounting rubber grommet | [link](https://click.world.taobao.com/_b.KcEIzp) | TaoBao | 1 | 0.48 |
| Drone Parts | RATE M10 GPS | Nano size gps module with battery | [link](https://click.world.taobao.com/_b.tcEIm7) | TaoBao | 1 | 8.80 |
| Drone Parts | 470uF low ESR capacitor | Capacitor for MOSFET protection | [link](https://click.world.taobao.com/_b.ecEuQ7) | TaoBao | 1 | 0.42 |
| Drone Parts | Cyclone 1W VTX | 5.8GHz analog video transmitter | [link](https://click.world.taobao.com/_b.zcEIzr) | TaoBao | 1 | 14.00 |
| Drone Parts | TaoBao Tax | Fees | - | TaoBao | 1 | 10.05 |
| Drone Parts | TaoBao Shipping | Shipping | - | TaoBao | 1 | 4.05 |
| Drone Parts | CADDX Ratel 2 + Tax | 19mm Analog camera | [link](https://www.aliexpress.com/item/1005009304280288.html) | AliExpress | 1 | 28.64 |
| Drone Parts | AliExpress Shipping | Shipping | - | AliExpress | 1 | 0.99 |
| Drone Parts | GNB LiHV 4S 850mAh | 4S LiHV battery | [link](https://shopee.com.my/Gaoneng-GNB-15.2HV-850mAh-120C-4S-Lipo-Battery-with-XT30-Plug-GNB850-120-4S-i.92575144.18545880487) | Shopee | 1 | 20.10 |

- **Flight Controller Total:** $89.42
- **ESC Total:** $33.95
- **Shipping Total:** $26.50
- **Drone Parts Total:** $134.16
### **Grand Total:** $284.03

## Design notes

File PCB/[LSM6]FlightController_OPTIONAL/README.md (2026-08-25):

Almomst identical to the MPU6500 version of the board, but the footprint is changed to support LSM6 (LSM6DSK320X/LSM6DSV16X/LSM6DSO/LSM6DSOX) series gyro which has superior noise rejection compared to MPU6500 in high vibration environments.

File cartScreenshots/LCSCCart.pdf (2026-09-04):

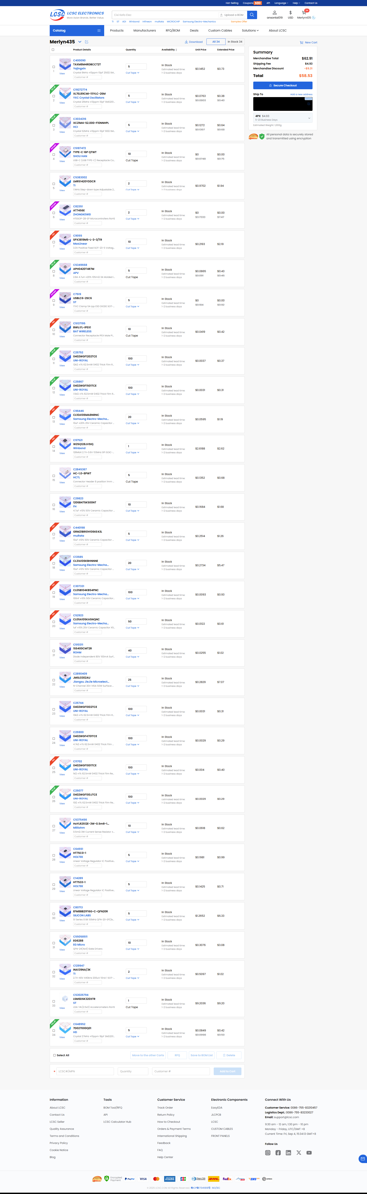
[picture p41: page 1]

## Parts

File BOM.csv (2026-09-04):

Category | Item Name | Description | Link | Vendor | Quantity | Total Price (USD)
Flight Controller | TAXM8M4RDBCCT2T | 8 MHz crystal | https://www.lcsc.com/product-detail/C400090.html | LCSC | 5 | 0.73
Flight Controller | 7D027000I01 | 27 MHz crystal | https://www.lcsc.com/product-detail/C648952.html | LCSC | 5 | 0.50
Flight Controller | XL7EL89CMI-111YLC-26M | 26 MHz crystal | https://www.lcsc.com/product-detail/C19272774.html | LCSC | 5 | 0.44
Flight Controller | XC21M4-52.000-F10NNHPL | 52 MHz crystal | https://www.lcsc.com/product-detail/C3034316.html | LCSC | 5 | 0.68
Flight Controller | TYPE-C 16P QTWT | USB C Connector SMT | https://www.lcsc.com/product-detail/C5187472.html | LCSC | 10 | 0.75
Flight Controller | LMR51420YDDCR | Buck converter | https://www.lcsc.com/product-detail/C5383002.html | LCSC | 2 | 1.96
Flight Controller | AT7456E | Video overlay OSD | https://www.lcsc.com/product-detail/C82351.html | LCSC | 2 (Two because there's a deal on LCSC that lets me get both for free) | 7.49
Flight Controller | SPX3819M5-L-3-3/TR | 3.3v LDO regulator | https://www.lcsc.com/product-detail/C9055.html | LCSC | 10 | 2.19
Flight Controller | APH0420T4R7M | 4.7uH inductor | https://www.lcsc.com/product-detail/C5349668.html | LCSC | 5 | 0.45
Flight Controller | USBLC6-2SC6 | USB ESD protection | https://www.lcsc.com/product-detail/C7519.html | LCSC | 5 | 0.92
Flight Controller | BWU.FL-IPEX1 | U.FL connector | https://www.lcsc.com/product-detail/C5137195.html | LCSC | 10 | 0.42
Flight Controller | 0402WGF1202TCE | 12k 0402 resistor | https://www.lcsc.com/product-detail/C25752.html | LCSC | 100 | 0.69
Flight Controller | 0402WGF1501TCE | 1.5k 0402 resistor | https://www.lcsc.com/product-detail/C25867.html | LCSC | 100 | 0.50
Flight Controller+ESC | CL10A106MA8NRNC | 10uF 0603 capacitor | https://www.lcsc.com/product-detail/C96446.html | LCSC | 20 | 1.60
Flight Controller | 1206B475K500NT | 4.7uF 1206 capacitor | https://www.lcsc.com/product-detail/C29823.html | LCSC | 10 | 2.72
Flight Controller | W25Q128JVSIQ | 16MB flash chip | https://www.lcsc.com/product-detail/C97521.html | LCSC | 1 | 2.62
Flight Controller | HC-1.0-8PWT | JST SH 8p connector | https://www.lcsc.com/product-detail/C2845367.html | LCSC | 5 | 0.67
Flight Controller | LSM6DSK320XTR | LSM6 series IMU | https://www.lcsc.com/product-detail/C53025794.html | LCSC | 1 | 9.18
Flight Controller | PCB | PCB | - | JLCPCB | 1 | 7.00
Flight Controller | Partial PCB Assembly | Partial PCB Assembly | - | JLCPCB | 1 | 47.91
ESC | GRM21BR61H106KE43L | 10uF 0805 capacitor | https://www.lcsc.com/product-detail/C440198.html | LCSC | 5 | 1.25
ESC | CL31A106KBHNNNE | 10uF 1206 capacitor | https://www.lcsc.com/product-detail/C13585.html | LCSC | 20 | 5.63
ESC | CL05B104KB54PNC | 0.1uF 0402 capacitor | https://www.lcsc.com/product-detail/C307331.html | LCSC | 100 | 0.93
ESC | CL05A105KA5NQNC | 1uF 0402 capacitor | https://www.lcsc.com/product-detail/C52923.html | LCSC | 50 | 0.61
ESC | 1SS400CMT2R | SOD923 diode | https://www.lcsc.com/product-detail/C510311.html | LCSC | 40 | 1.02
ESC | JMSL0302AU | N channel MOSFET | https://www.lcsc.com/product-detail/C2890409.html | LCSC | 25 | 7.07
ESC | 0402WGF1002TCE | 10k 0402 resistor | https://www.lcsc.com/product-detail/C25744.html | LCSC | 100 | 0.19
ESC | 0402WGF4701TCE | 4.7k 0402 resistor | https://www.lcsc.com/product-detail/C25900.html | LCSC | 100 | 0.50
ESC | 0402WGF1001TCE | 1k 0402 resistor | https://www.lcsc.com/product-detail/C11702.html | LCSC | 100 | 0.67
ESC | 0402WGF100JTCE | 10R 0402 resistor | https://www.lcsc.com/product-detail/C25077.html | LCSC | 100 | 0.58
ESC | HoYLR2512E-3W-0.5mR-1% | 0.5mR 2512 shunt resistor | https://www.lcsc.com/product-detail/C5375456.html | LCSC | 10 | 0.60
ESC | 0402WGF3902TCE | 39k 0402 resistor | https://www.lcsc.com/product-detail/C25783.html | LCSC | 100 | 0.69
ESC | HT75C0-1 | 12v LDO regulator | https://www.lcsc.com/product-detail/C64551.html | LCSC | 5 | 0.99
ESC | HT7533-1 | 3.3v LDO regulator | https://www.lcsc.com/product-detail/C14289.html | LCSC | 5 | 0.71
ESC | EFM8BB21F16G-C-QFN20R | ESC MCU | https://www.lcsc.com/product-detail/C80713.html | LCSC | 5 | 6.33
ESC | EG6288 | Gate driver | https://www.lcsc.com/product-detail/C55058511.html | LCSC | 10 | 3.06
ESC | INA139NA/3K | Current sensor | https://www.lcsc.com/product-detail/C129947.html | LCSC | 2 | 1.12
ESC | PCB | PCB | - | JLCPCB | 1 | 2.00
Flight Controller + ESC | Shipping | EPOST shipping | - | JLCPCB | 1 | 6.49
Flight Controller + ESC | Shipping | LCSC | - | LCSC | 1 | 4.92
Drone Parts | RATE 1505 4300kv motor | Motors | https://click.world.taobao.com/_b.RcEIyQ | TaoBao | 4 | 28.75
Drone Parts | RATE S30 Pro frame | Carbon fiber frame | https://click.world.taobao.com/_b.6cEImS | TaoBao | 1 | 23.06
Drone Parts | RATE analog antenna | Right hand circular polarized 5.8GHz antenna | https://click.world.taobao.com/_b.ecEImU | TaoBao | 1 | 5.80
Drone Parts | RATE 90mm ELRS antenna | Linear polarized dipole 2.4GHz antenna | https://click.world.taobao.com/_b.3cEIO4 | TaoBao | 1 | 0.95
Drone Parts | RATE beeper/buzzer | Active piezo buzzer | https://click.world.taobao.com/_b.VcEIzD | TaoBao | 1 | 0.64
Drone Parts | HQPROP T3x3x3 | 2 Pairs 3 inch propeller | https://click.world.taobao.com/_b.0cEJ5z | TaoBao | 1 | 1.88
Drone Parts | RATE XT30 + Cable | Connector and cable | https://click.world.taobao.com/_b.acEJqe | TaoBao | 1 | 0.64
Drone Parts | RATE Rubber Grommets | 10pcs soft mounting rubber grommet | https://click.world.taobao.com/_b.KcEIzp | TaoBao | 1 | 0.48
Drone Parts | RATE M10 GPS | Nano size gps module with battery | https://click.world.taobao.com/_b.tcEIm7 | TaoBao | 1 | 8.80
Drone Parts | 470uF low ESR capacitor | Capacitor for MOSFET protection | https://click.world.taobao.com/_b.ecEuQ7 | TaoBao | 1 | 0.42
Drone Parts | Cyclone 1W VTX | 5.8GHz analog video transmitter | https://click.world.taobao.com/_b.zcEIzr | TaoBao | 1 | 14.00
Drone Parts | TaoBao Tax | Fees | - | TaoBao | 1 | 10.05
Drone Parts | TaoBao Shipping | Shipping | - | TaoBao | 1 | 4.05
Drone Parts | CADDX Ratel 2 + Tax | 19mm Analog camera | https://www.aliexpress.com/item/1005009304280288.html | AliExpress | 1 | 28.64
Drone Parts | AliExpress Shipping | Shipping | - | AliExpress | 1 | 0.99
Drone Parts | GNB LiHV 4S 850mAh | 4S LiHV battery | https://shopee.com.my/Gaoneng-GNB-15.2HV-850mAh-120C-4S-Lipo-Battery-with-XT30-Plug-GNB850-120-4S-i.92575144.18545880487 | Shopee | 1 | 20.10
Flight Controller Total | 89.42
ESC Total | 33.95
Shipping Total | 26.50
Drone Parts Total | 134.16
Grand Total | 284.03

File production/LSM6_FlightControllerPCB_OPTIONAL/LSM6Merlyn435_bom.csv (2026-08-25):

Designator | Footprint | Quantity | Value | LCSC Part #
C1, C10, C11, C13, C14, C15, C19, C22, C24, C25, C26, C29, C30, C33, C34, C35, C36, C37, C39, C40, C41, C42, C5 | 0402 | 23 | 0.1uF | C307331
C12, C23, C38 | 0402 | 3 | 10uF | C15525
C16, C17, C31, C32 | 0402 | 4 | 10pF | C32949
C18, C20, C8 | 0402 | 3 | 10nF | C15195
C2, C3, C6, C7 | 0603 | 4 | 10uF | C96446
C21 | 0402 | 1 | 470nF | C47339
C27, C28 | 0805 | 2 | 22uF | C45783
D2 | LED0805-RD | 1 | RED | C84256
D3 | LED0805-R-RD | 1 | GREEN | C2297
R1, R14, R15, R16, R19, R25, R4, R6, R8, R9 | 0402 | 10 | 12k | C25752
R10, R11, R17, R18, R21, R22 | 0402 | 6 | 5.1k | C25905
R12, R13 | 0402 | 2 | 75 | C25133
R2 | 0402 | 1 | 15k | C25756
R23 | 0603 | 1 | 91k | C23265
R3 | 0402 | 1 | 2k | C4109
U1 | QFN-48_L6.0-W6.0-P0.40-TL-EP3.2 | 1 | AT32F435CGU7 | C5178937
U17 | LGA-14_L3.0-W2.5-P0.50-TL | 1 | LSM6DSK320XTR | C53025794
U2 | QFN-32_L5.0-W5.0-P0.50-TL-EP3.7 | 1 | ESP8285H16 | C967019
U5 | QFN-24_L4.0-W4.0-P0.50-TL-EP2.6 | 1 | SX1281IMLTRT | C2151551
U6 | LGA-10_L2.0-W2.0-P0.50-BL | 1 | BMP388 | C54582187

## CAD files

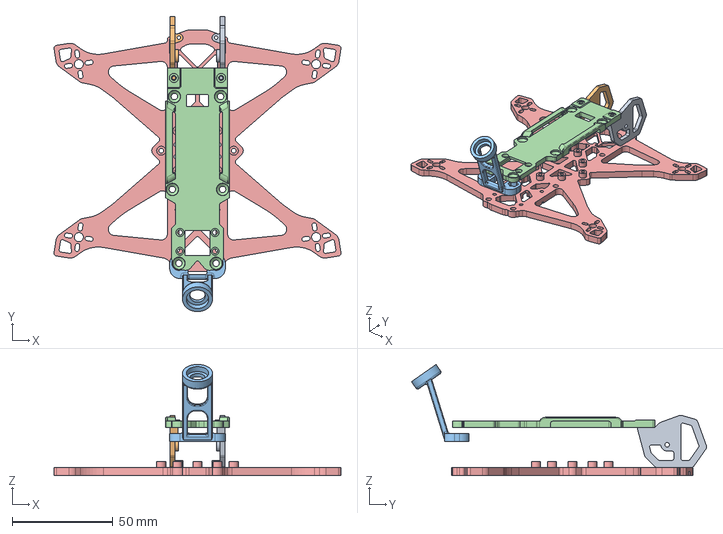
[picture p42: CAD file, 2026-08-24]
CAD/Merlyn411Frame3inVer.step
142.7 x 146.8 x 55.2 mm

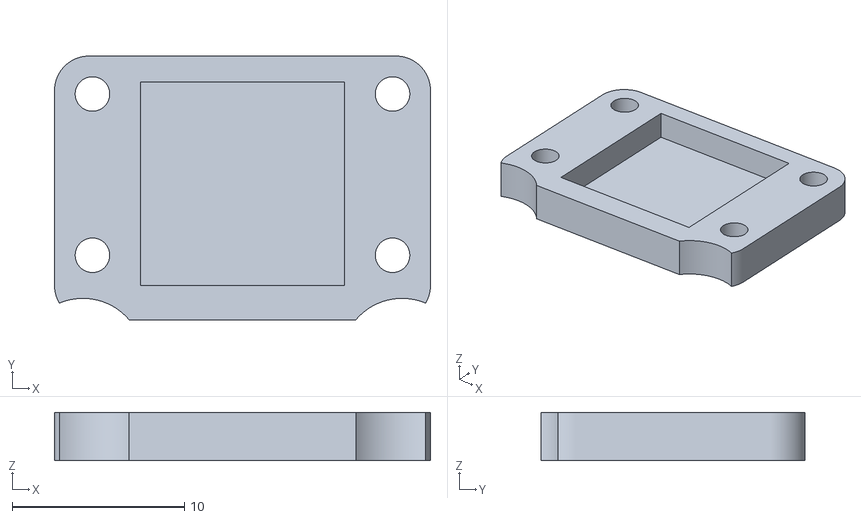
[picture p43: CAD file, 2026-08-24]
production/3dPrint/gpsLock.stl
21.8 x 15.3 x 2.80

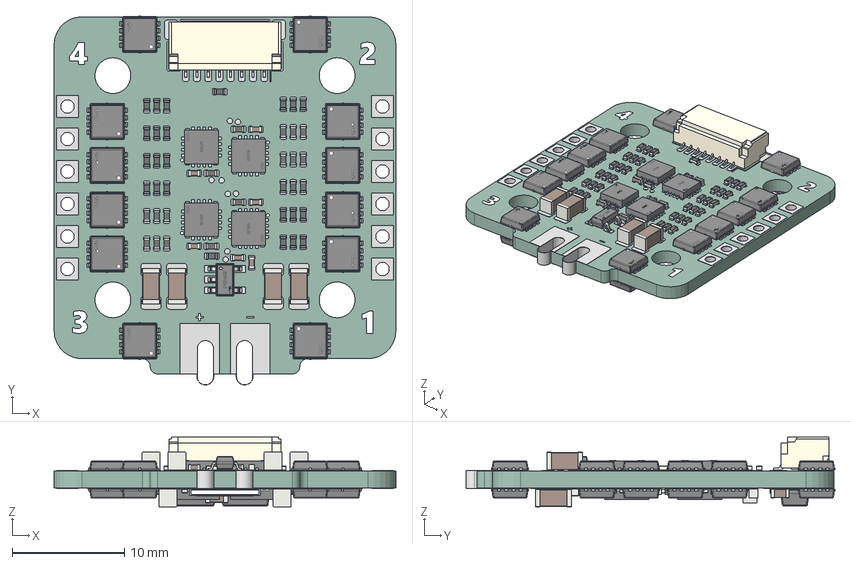
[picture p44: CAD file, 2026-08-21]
CAD/MerlynESC.step
30.5 x 32.9 x 6.23 mm
R_0402_1005Metric x 66
C_0402_1005Metric x 22
C_1206_3216Metric x 6
PDFN3333-8_L3.1-W3.2-H0.8-P0.65 x 24
SM08B-SRSS-TB (LF)(SN)--3DModel-STEP-269445
QFN-20_L3.0-W3.0-H0.8-P0.50 x 4
SOT-23-5_L2.9-W1.6-H1.1-LS2.8-P0.95
D_SOD-923 x 12
C_0805_2012Metric
QFN-24_L4.0-W4.0-P0.50-TL-EP2.6 x 4
R2512_L6.3-W3.2-H0.6
C_0603_1608Metric x 2
SOT-89-3_L4.3-W2.5-H1.6-LS4.1-P1.50 x 2
MerlynESC_pad
MerlynESC_silkscreen x 2
MerlynESC_PCB

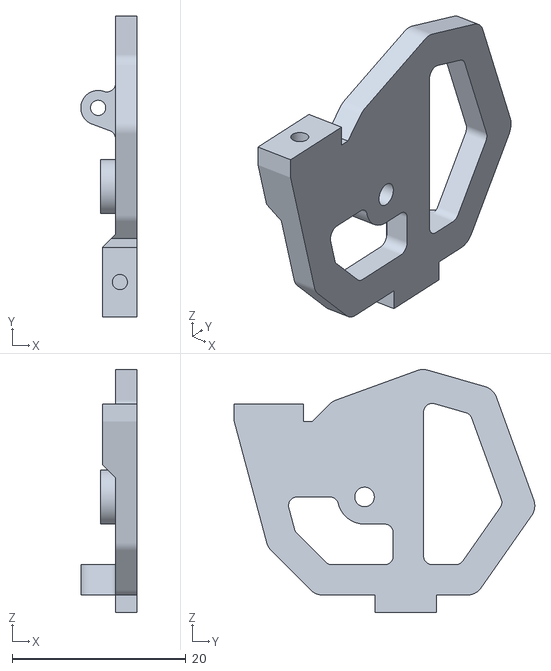
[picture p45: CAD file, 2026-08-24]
production/3dPrint/rightCameraFrameReinforced.stl
6.50 x 34.6 x 28.0

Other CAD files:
production/3dPrint/leftCameraFrameReinforced.stl
CAD/Merlyn411Frame3inVer.f3d

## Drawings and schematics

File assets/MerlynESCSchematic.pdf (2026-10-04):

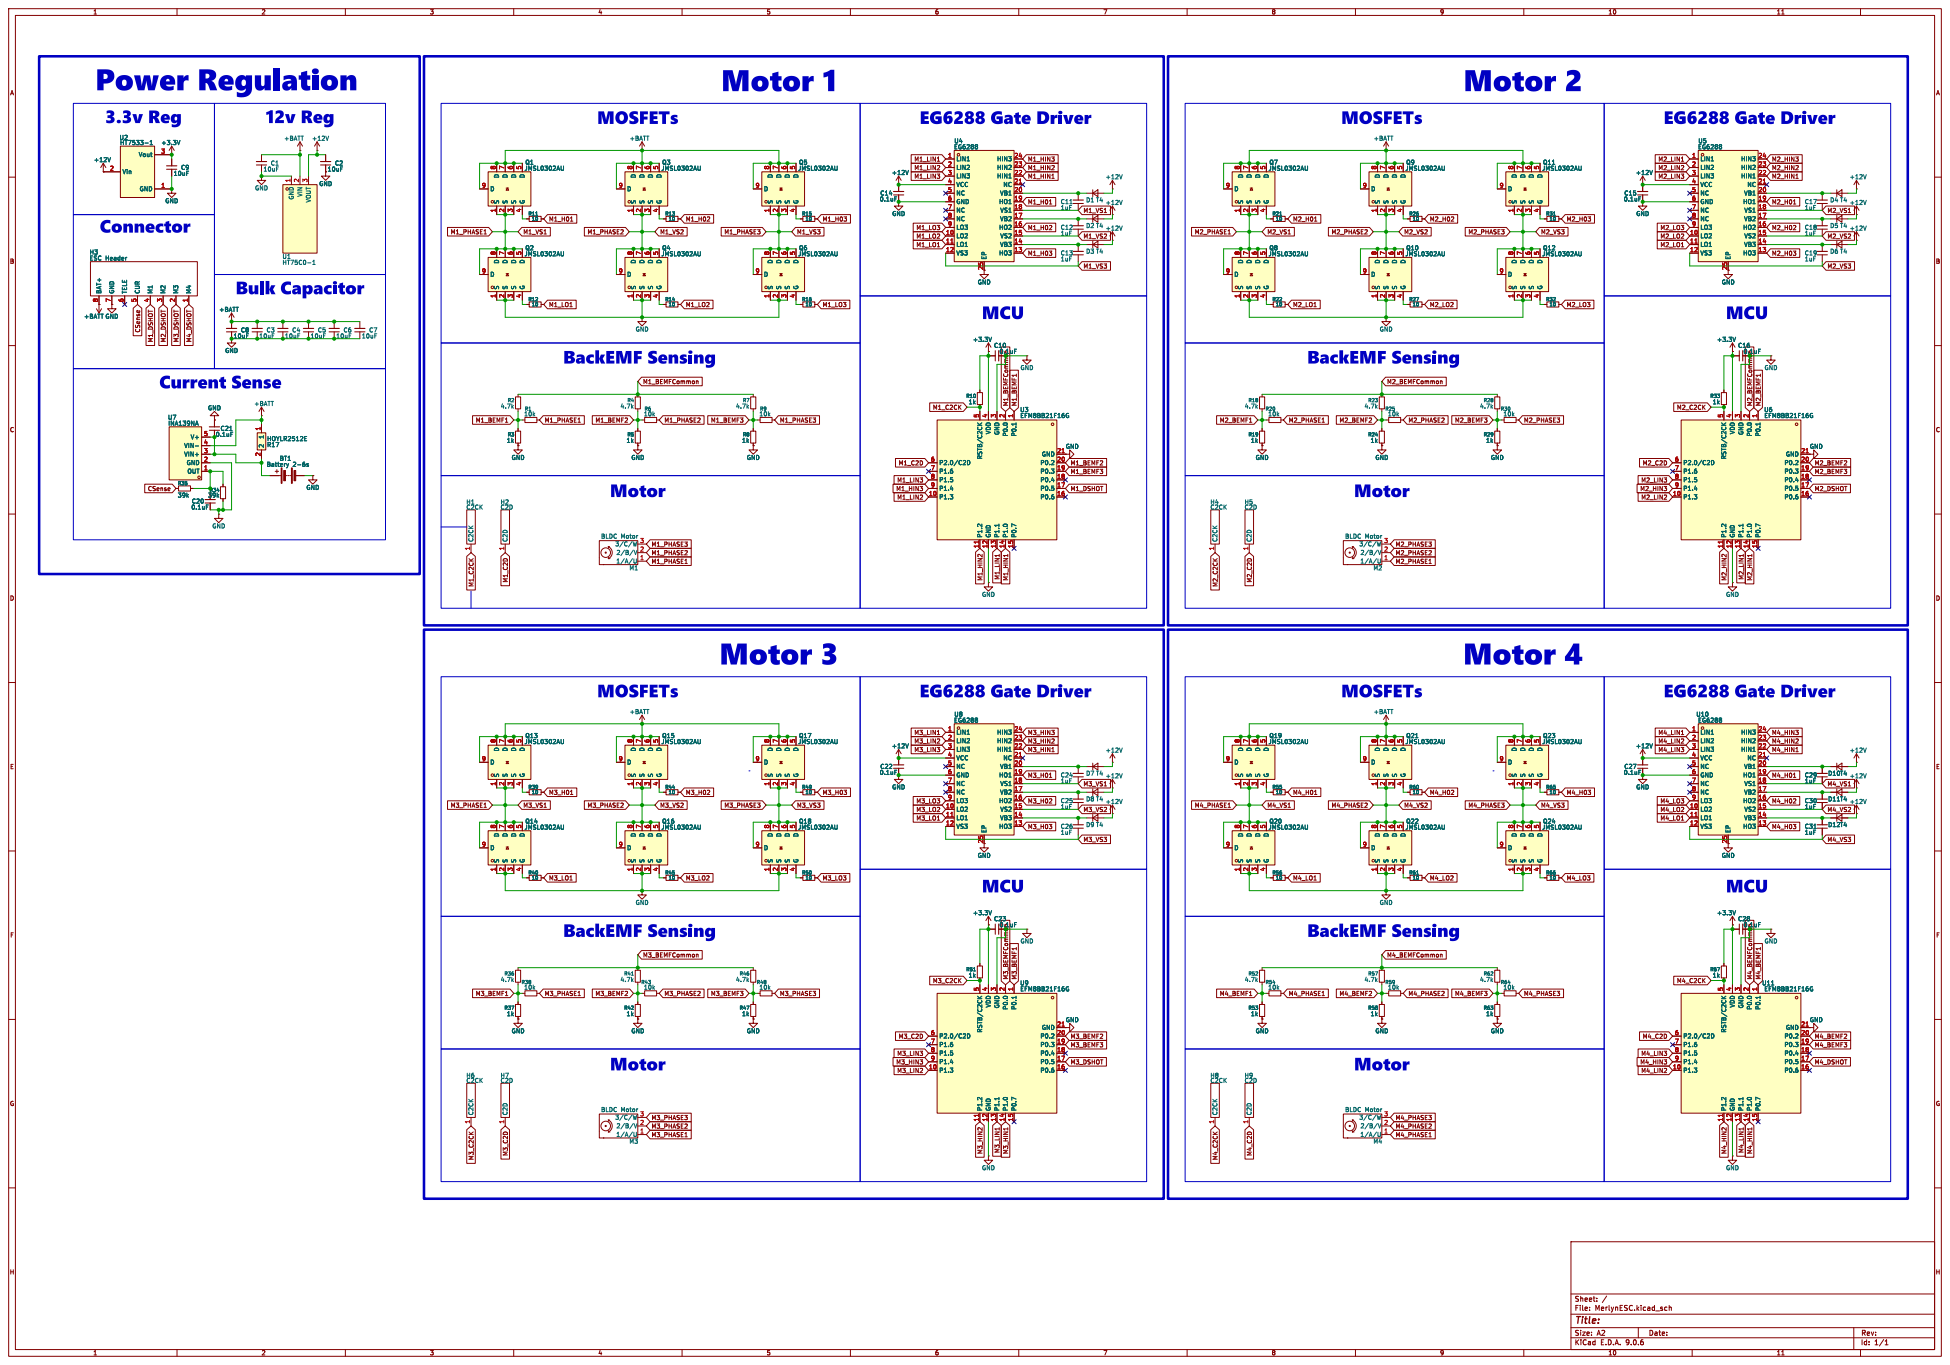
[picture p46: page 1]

+BATT H3 ESC Header BAT+

5 GND 21 P0.2 20 P2.0/C2D 6 P0.3 19 P1.6 7 P0.4 18 P1.5 8 P0.5 17 P1.4 9 P0.6 16 P1.3 10 P0.7 15 P1.0 14 P1.1 13 GND 12 P1.2 11 GND GND

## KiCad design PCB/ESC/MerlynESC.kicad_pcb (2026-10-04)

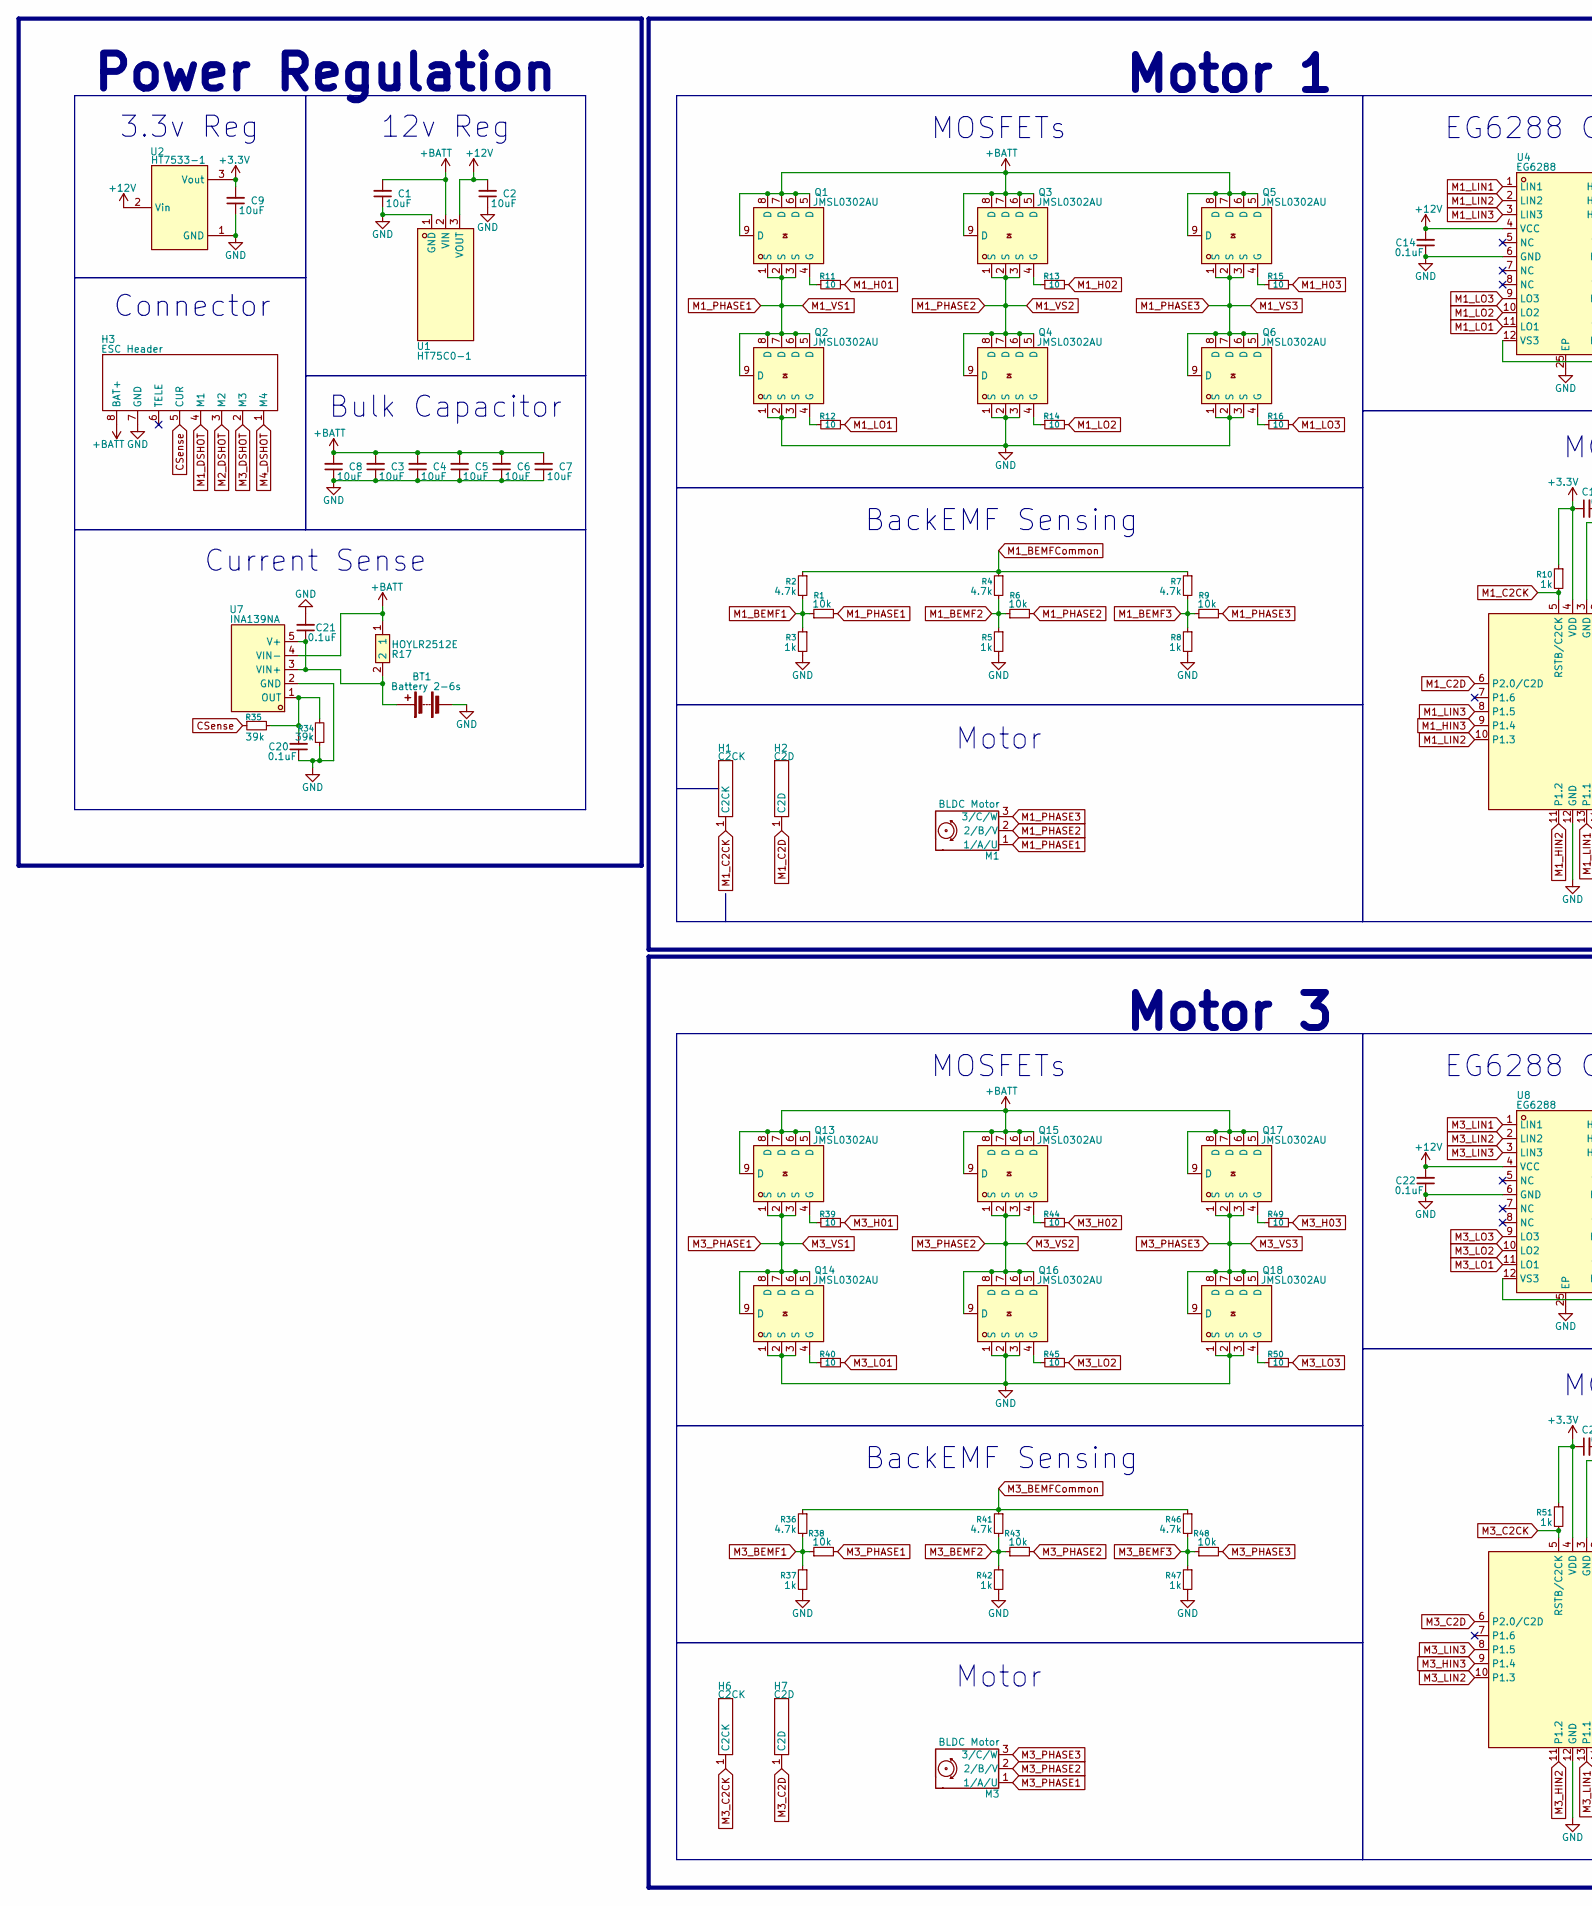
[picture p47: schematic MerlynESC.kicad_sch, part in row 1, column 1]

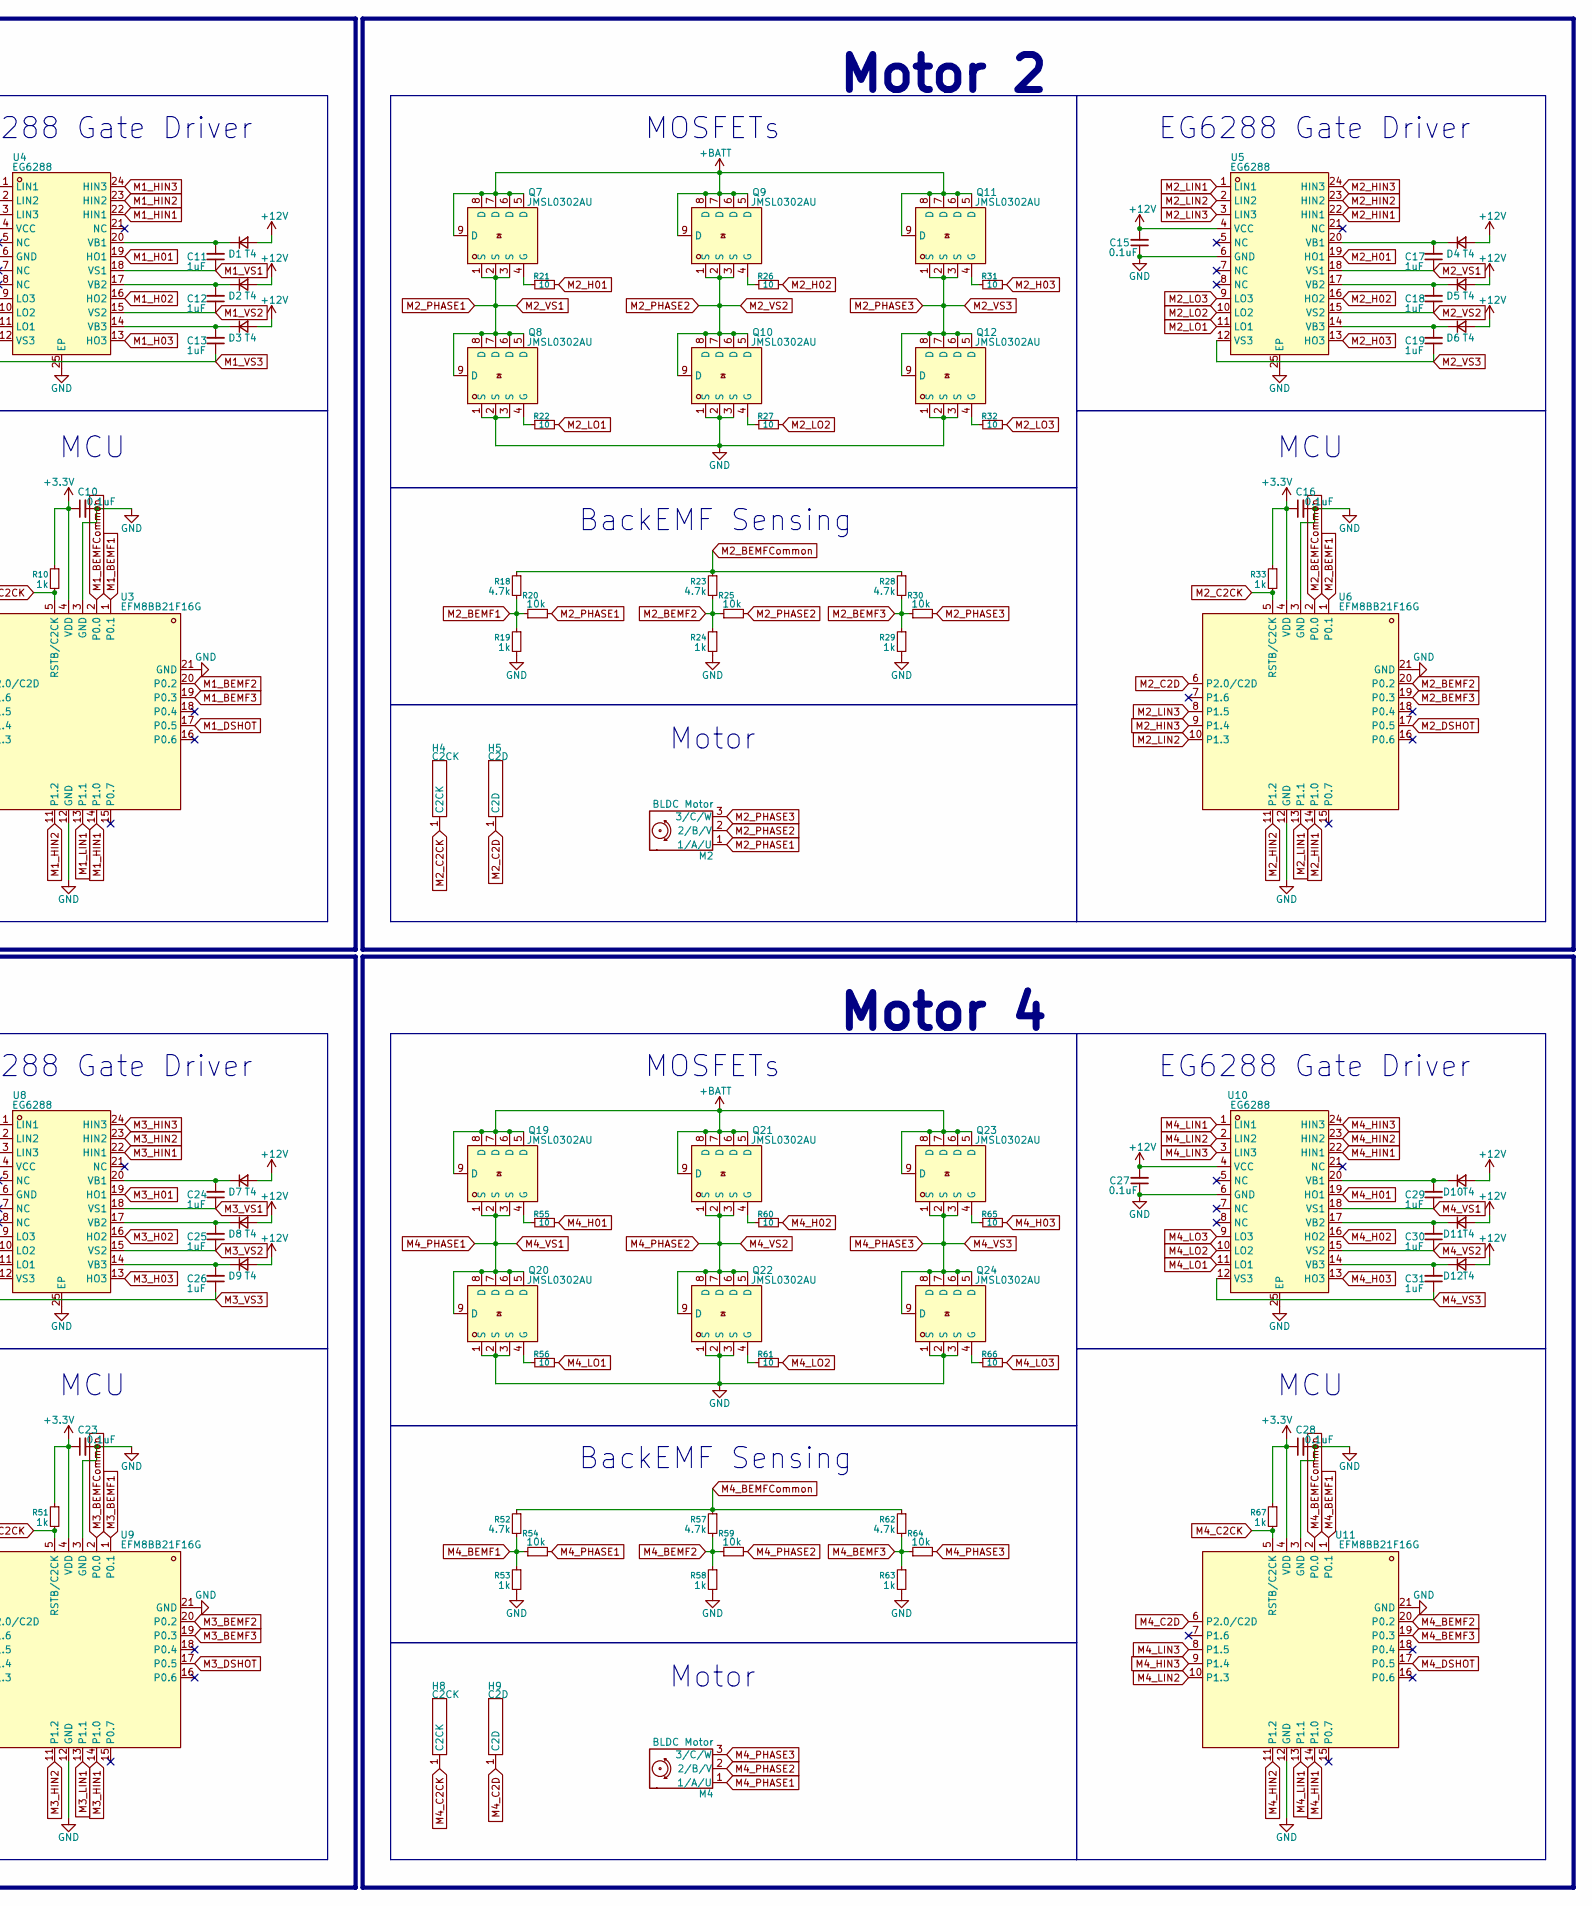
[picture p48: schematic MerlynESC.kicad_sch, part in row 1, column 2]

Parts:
BT1: Battery 2-6s; PowerPad
C1: 10uF; C_0805_2012Metric; LCSC Part C440198
C2, C9: 10uF; C_0603_1608Metric; LCSC Part C96446
C3, C4, C5, C6, C7, C8: 10uF; C_1206_3216Metric; LCSC Part C13585
C10, C14, C15, C16, C20, C21, C22, C23, C27, C28: 0.1uF; C_0402_1005Metric; LCSC Part C307331
C11, C12, C13, C17, C18, C19, C24, C25, C26, C29, C30, C31: 1uF; C_0402_1005Metric; LCSC Part C52923
D1, D2, D3, D4, D5, D6, D7, D8, D9, D10, D11, D12: T4; D_SOD-923; LCSC Part C510311
H1, H4, H6, H8: C2CK; TestPoint
H2, H5, H7, H9: C2D; TestPoint
H3: ESC Header
M1, M2, M3, M4: BLDC Motor; MotorPad
Q1, Q2, Q3, Q4, Q5, Q6, Q7, Q8, Q9, Q10, Q11, Q12, Q13, Q14, Q15, Q16, Q17, Q18, Q19, Q20, Q21, Q22, Q23, Q24: JMSL0302AU; DFN-8_L3.2-W3.1-P0.65-LS3.4-BL; MPN JMSL0302AU; LCSC Part C2890409
R1, R6, R9, R20, R25, R30, R38, R43, R48, R54, R59, R64: 10k; R_0402_1005Metric; LCSC Part C25744
R2, R4, R7, R18, R23, R28, R36, R41, R46, R52, R57, R62: 4.7k; R_0402_1005Metric; LCSC Part C25900
R3, R5, R8, R10, R19, R24, R29, R33, R37, R42, R47, R51, R53, R58, R63, R67: 1k; R_0402_1005Metric; LCSC Part C11702
R11, R12, R13, R14, R15, R16, R21, R22, R26, R27, R31, R32, R39, R40, R44, R45, R49, R50, R55, R56, R60, R61, R65, R66: 10; R_0402_1005Metric; LCSC Part C25077
R17: HOYLR2512E; R2512; MPN HoYLR2512E-3W-0.5mR-1%; LCSC Part C5375456
R34, R35: 39k; R_0402_1005Metric; LCSC Part C25783
U1: HT75C0-1; SOT-89-3_L4.5-W2.5-P1.50-LS4.2-BR; MPN HT75C0-1; LCSC Part C64551
U2: HT7533-1; SOT-89-3_L4.5-W2.5-P1.50-LS4.2-BR; MPN HT7533-1; LCSC Part C14289
U3, U6, U9, U11: EFM8BB21F16G; QFN-20_L3.0-W3.0-P0.50-BL-EP1.7_EFM8BB21F16G; MPN EFM8BB21F16G-C-QFN20R; LCSC Part C80713
U4, U5, U8, U10: EG6288; QFN-24_L4.0-W4.0-P0.50-TL-EP2.6; MPN EG6288; LCSC Part C55058511
U7: INA139NA; SOT-23-5_L3.0-W1.7-P0.95-LS2.8-BR; MPN INA139NA/3K; LCSC Part C129947

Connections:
+3.3V: C9.2, C10.1, C16.1, C23.1, C28.1, R10.1, R33.1, R51.1, R67.1, U2.3 (Vout), U3.4 (VDD), U6.4 (VDD), U9.4 (VDD), U11.4 (VDD)
+12V: C2.2, C14.2, C15.2, C22.2, C27.2, D1.2 (A), D2.2 (A), D3.2 (A), D4.2 (A), D5.2 (A), D6.2 (A), D7.2 (A), D8.2 (A), D9.2 (A), D10.2 (A), D11.2 (A), D12.2 (A), U1.3 (VOUT), U2.2 (Vin), U4.4 (VCC), U5.4 (VCC), U8.4 (VCC), U10.4 (VCC)
+BATT: C1.2, C3.2, C4.2, C5.2, C6.2, C7.2, C8.2, H3.8 (BAT+), Q1.5 (D), Q1.6 (D), Q1.7 (D), Q1.8 (D), Q1.9 (D), Q3.5 (D), Q3.6 (D), Q3.7 (D), Q3.8 (D), Q3.9 (D), Q5.5 (D), Q5.6 (D), Q5.7 (D), Q5.8 (D), Q5.9 (D), Q7.5 (D), Q7.6 (D), Q7.7 (D), Q7.8 (D), Q7.9 (D), Q9.5 (D), Q9.6 (D), Q9.7 (D), Q9.8 (D), Q9.9 (D), Q11.5 (D), Q11.6 (D), Q11.7 (D), Q11.8 (D), Q11.9 (D), Q13.5 (D), Q13.6 (D), Q13.7 (D), Q13.8 (D), Q13.9 (D), Q15.5 (D), Q15.6 (D), Q15.7 (D), Q15.8 (D), Q15.9 (D), Q17.5 (D), Q17.6 (D), Q17.7 (D), Q17.8 (D), Q17.9 (D), Q19.5 (D), Q19.6 (D), Q19.7 (D), Q19.8 (D), Q19.9 (D), Q21.5 (D), Q21.6 (D), Q21.7 (D), Q21.8 (D), Q21.9 (D), Q23.5 (D), Q23.6 (D), Q23.7 (D), Q23.8 (D), Q23.9 (D), R17.1, U1.2 (VIN), U7.4 (VIN-)
CSense: H3.5 (CUR), R35.1
GND: BT1.2 (-), C1.1, C2.1, C3.1, C4.1, C5.1, C6.1, C7.1, C8.1, C9.1, C10.2, C14.1, C15.1, C16.2, C20.1, C21.2, C22.1, C23.2, C27.1, C28.2, H3.7 (GND), Q2.1 (S), Q2.2 (S), Q2.3 (S), Q4.1 (S), Q4.2 (S), Q4.3 (S), Q6.1 (S), Q6.2 (S), Q6.3 (S), Q8.1 (S), Q8.2 (S), Q8.3 (S), Q10.1 (S), Q10.2 (S), Q10.3 (S), Q12.1 (S), Q12.2 (S), Q12.3 (S), Q14.1 (S), Q14.2 (S), Q14.3 (S), Q16.1 (S), Q16.2 (S), Q16.3 (S), Q18.1 (S), Q18.2 (S), Q18.3 (S), Q20.1 (S), Q20.2 (S), Q20.3 (S), Q22.1 (S), Q22.2 (S), Q22.3 (S), Q24.1 (S), Q24.2 (S), Q24.3 (S), R3.2, R5.2, R8.2, R19.2, R24.2, R29.2, R34.1, R37.2, R42.2, R47.2, R53.2, R58.2, R63.2, U1.1 (GND), U2.1 (GND), U3.3 (GND), U3.12 (GND), U3.21 (GND), U4.6 (GND), U4.25 (EP), U5.6 (GND), U5.25 (EP), U6.3 (GND), U6.12 (GND), U6.21 (GND), U7.2 (GND), U8.6 (GND), U8.25 (EP), U9.3 (GND), U9.12 (GND), U9.21 (GND), U10.6 (GND), U10.25 (EP), U11.3 (GND), U11.12 (GND), U11.21 (GND)
M1_BEMF1: R1.1, R2.2, R3.1, U3.1 (P0.1)
M1_BEMF2: R4.2, R5.1, R6.1, U3.20 (P0.2)
M1_BEMF3: R7.2, R8.1, R9.1, U3.19 (P0.3)
M1_BEMFCommon: R2.1, R4.1, R7.1, U3.2 (P0.0)
M1_C2CK: H1.1 (C2CK), R10.2, U3.5 (RSTB/C2CK)
M1_C2D: H2.1 (C2D), U3.6 (P2.0/C2D)
M1_DSHOT: H3.4 (M1), U3.17 (P0.5)
M1_H01: R11.2, U4.19 (HO1)
M1_H02: R13.2, U4.16 (HO2)
M1_H03: R15.2, U4.13 (HO3)
M1_HIN1: U3.14 (P1.0), U4.22 (HIN1)
M1_HIN2: U3.11 (P1.2), U4.23 (HIN2)
M1_HIN3: U3.9 (P1.4), U4.24 (HIN3)
M1_LIN1: U3.13 (P1.1), U4.1 (LIN1)
M1_LIN2: U3.10 (P1.3), U4.2 (LIN2)
M1_LIN3: U3.8 (P1.5), U4.3 (LIN3)
M1_LO1: R12.2, U4.11 (LO1)
M1_LO2: R14.2, U4.10 (LO2)
M1_LO3: R16.2, U4.9 (LO3)
M1_PHASE1: C11.1, M1.1 (1/A/U), Q1.1 (S), Q1.2 (S), Q1.3 (S), Q2.5 (D), Q2.6 (D), Q2.7 (D), Q2.8 (D), Q2.9 (D), R1.2, U4.18 (VS1)
M1_PHASE2: C12.1, M1.2 (2/B/V), Q3.1 (S), Q3.2 (S), Q3.3 (S), Q4.5 (D), Q4.6 (D), Q4.7 (D), Q4.8 (D), Q4.9 (D), R6.2, U4.15 (VS2)
M1_PHASE3: C13.1, M1.3 (3/C/W), Q5.1 (S), Q5.2 (S), Q5.3 (S), Q6.5 (D), Q6.6 (D), Q6.7 (D), Q6.8 (D), Q6.9 (D), R9.2, U4.12 (VS3)
M2_BEMF1: R18.2, R19.1, R20.1, U6.1 (P0.1)
M2_BEMF2: R23.2, R24.1, R25.1, U6.20 (P0.2)
M2_BEMF3: R28.2, R29.1, R30.1, U6.19 (P0.3)
M2_BEMFCommon: R18.1, R23.1, R28.1, U6.2 (P0.0)
M2_C2CK: H4.1 (C2CK), R33.2, U6.5 (RSTB/C2CK)
M2_C2D: H5.1 (C2D), U6.6 (P2.0/C2D)
M2_DSHOT: H3.3 (M2), U6.17 (P0.5)
M2_H01: R21.2, U5.19 (HO1)
M2_H02: R26.2, U5.16 (HO2)
M2_H03: R31.2, U5.13 (HO3)
M2_HIN1: U5.22 (HIN1), U6.14 (P1.0)
M2_HIN2: U5.23 (HIN2), U6.11 (P1.2)
M2_HIN3: U5.24 (HIN3), U6.9 (P1.4)
M2_LIN1: U5.1 (LIN1), U6.13 (P1.1)
M2_LIN2: U5.2 (LIN2), U6.10 (P1.3)
M2_LIN3: U5.3 (LIN3), U6.8 (P1.5)
M2_LO1: R22.2, U5.11 (LO1)
M2_LO2: R27.2, U5.10 (LO2)
M2_LO3: R32.2, U5.9 (LO3)
M2_PHASE1: C17.1, M2.1 (1/A/U), Q7.1 (S), Q7.2 (S), Q7.3 (S), Q8.5 (D), Q8.6 (D), Q8.7 (D), Q8.8 (D), Q8.9 (D), R20.2, U5.18 (VS1)
M2_PHASE2: C18.1, M2.2 (2/B/V), Q9.1 (S), Q9.2 (S), Q9.3 (S), Q10.5 (D), Q10.6 (D), Q10.7 (D), Q10.8 (D), Q10.9 (D), R25.2, U5.15 (VS2)
M2_PHASE3: C19.1, M2.3 (3/C/W), Q11.1 (S), Q11.2 (S), Q11.3 (S), Q12.5 (D), Q12.6 (D), Q12.7 (D), Q12.8 (D), Q12.9 (D), R30.2, U5.12 (VS3)
M3_BEMF1: R36.2, R37.1, R38.1, U9.1 (P0.1)
M3_BEMF2: R41.2, R42.1, R43.1, U9.20 (P0.2)
M3_BEMF3: R46.2, R47.1, R48.1, U9.19 (P0.3)
M3_BEMFCommon: R36.1, R41.1, R46.1, U9.2 (P0.0)
M3_C2CK: H6.1 (C2CK), R51.2, U9.5 (RSTB/C2CK)
M3_C2D: H7.1 (C2D), U9.6 (P2.0/C2D)
M3_DSHOT: H3.2 (M3), U9.17 (P0.5)
M3_H01: R39.2, U8.19 (HO1)
M3_H02: R44.2, U8.16 (HO2)
M3_H03: R49.2, U8.13 (HO3)
M3_HIN1: U8.22 (HIN1), U9.14 (P1.0)
M3_HIN2: U8.23 (HIN2), U9.11 (P1.2)
M3_HIN3: U8.24 (HIN3), U9.9 (P1.4)
M3_LIN1: U8.1 (LIN1), U9.13 (P1.1)
M3_LIN2: U8.2 (LIN2), U9.10 (P1.3)
M3_LIN3: U8.3 (LIN3), U9.8 (P1.5)
M3_LO1: R40.2, U8.11 (LO1)
M3_LO2: R45.2, U8.10 (LO2)
M3_LO3: R50.2, U8.9 (LO3)
M3_PHASE1: C24.1, M3.1 (1/A/U), Q13.1 (S), Q13.2 (S), Q13.3 (S), Q14.5 (D), Q14.6 (D), Q14.7 (D), Q14.8 (D), Q14.9 (D), R38.2, U8.18 (VS1)
M3_PHASE2: C25.1, M3.2 (2/B/V), Q15.1 (S), Q15.2 (S), Q15.3 (S), Q16.5 (D), Q16.6 (D), Q16.7 (D), Q16.8 (D), Q16.9 (D), R43.2, U8.15 (VS2)
M3_PHASE3: C26.1, M3.3 (3/C/W), Q17.1 (S), Q17.2 (S), Q17.3 (S), Q18.5 (D), Q18.6 (D), Q18.7 (D), Q18.8 (D), Q18.9 (D), R48.2, U8.12 (VS3)
M4_BEMF1: R52.2, R53.1, R54.1, U11.1 (P0.1)
M4_BEMF2: R57.2, R58.1, R59.1, U11.20 (P0.2)
M4_BEMF3: R62.2, R63.1, R64.1, U11.19 (P0.3)
M4_BEMFCommon: R52.1, R57.1, R62.1, U11.2 (P0.0)
M4_C2CK: H8.1 (C2CK), R67.2, U11.5 (RSTB/C2CK)
M4_C2D: H9.1 (C2D), U11.6 (P2.0/C2D)
M4_DSHOT: H3.1 (M4), U11.17 (P0.5)
M4_H01: R55.2, U10.19 (HO1)
M4_H02: R60.2, U10.16 (HO2)
M4_H03: R65.2, U10.13 (HO3)
M4_HIN1: U10.22 (HIN1), U11.14 (P1.0)
M4_HIN2: U10.23 (HIN2), U11.11 (P1.2)
M4_HIN3: U10.24 (HIN3), U11.9 (P1.4)
M4_LIN1: U10.1 (LIN1), U11.13 (P1.1)
M4_LIN2: U10.2 (LIN2), U11.10 (P1.3)
M4_LIN3: U10.3 (LIN3), U11.8 (P1.5)
M4_LO1: R56.2, U10.11 (LO1)
M4_LO2: R61.2, U10.10 (LO2)
M4_LO3: R66.2, U10.9 (LO3)
M4_PHASE1: C29.1, M4.1 (1/A/U), Q19.1 (S), Q19.2 (S), Q19.3 (S), Q20.5 (D), Q20.6 (D), Q20.7 (D), Q20.8 (D), Q20.9 (D), R54.2, U10.18 (VS1)
M4_PHASE2: C30.1, M4.2 (2/B/V), Q21.1 (S), Q21.2 (S), Q21.3 (S), Q22.5 (D), Q22.6 (D), Q22.7 (D), Q22.8 (D), Q22.9 (D), R59.2, U10.15 (VS2)
M4_PHASE3: C31.1, M4.3 (3/C/W), Q23.1 (S), Q23.2 (S), Q23.3 (S), Q24.5 (D), Q24.6 (D), Q24.7 (D), Q24.8 (D), Q24.9 (D), R64.2, U10.12 (VS3)
unnamed: BT1.1 (+), C21.1, R17.2, U7.3 (VIN+), U7.5 (V+)
unnamed: C11.2, D1.1 (K), U4.20 (VB1)
unnamed: C12.2, D2.1 (K), U4.17 (VB2)
unnamed: C13.2, D3.1 (K), U4.14 (VB3)
unnamed: C17.2, D4.1 (K), U5.20 (VB1)
unnamed: C18.2, D5.1 (K), U5.17 (VB2)
unnamed: C19.2, D6.1 (K), U5.14 (VB3)
unnamed: C24.2, D7.1 (K), U8.20 (VB1)
unnamed: C25.2, D8.1 (K), U8.17 (VB2)
unnamed: C26.2, D9.1 (K), U8.14 (VB3)
unnamed: C29.2, D10.1 (K), U10.20 (VB1)
unnamed: C30.2, D11.1 (K), U10.17 (VB2)
unnamed: C31.2, D12.1 (K), U10.14 (VB3)
unnamed: Q1.4 (G), R11.1
unnamed: Q2.4 (G), R12.1
unnamed: Q3.4 (G), R13.1
unnamed: Q4.4 (G), R14.1
unnamed: Q5.4 (G), R15.1
unnamed: Q6.4 (G), R16.1
unnamed: Q7.4 (G), R21.1
unnamed: Q8.4 (G), R22.1
unnamed: Q9.4 (G), R26.1
unnamed: Q10.4 (G), R27.1
unnamed: Q11.4 (G), R31.1
unnamed: Q12.4 (G), R32.1
unnamed: Q13.4 (G), R39.1
unnamed: Q14.4 (G), R40.1
unnamed: Q15.4 (G), R44.1
unnamed: Q16.4 (G), R45.1
unnamed: Q17.4 (G), R49.1
unnamed: Q18.4 (G), R50.1
unnamed: Q19.4 (G), R55.1
unnamed: Q20.4 (G), R56.1
unnamed: Q21.4 (G), R60.1
unnamed: Q22.4 (G), R61.1
unnamed: Q23.4 (G), R65.1
unnamed: Q24.4 (G), R66.1
unnamed: C20.2, R34.2, R35.2, U7.1 (OUT)

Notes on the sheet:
Connector
Motor
12v Reg
MOSFETs
Motor 3
MCU
EG6288 Gate Driver
Current Sense
BackEMF Sensing
3.3v Reg
Motor 1
Motor 4
Bulk Capacitor
Power Regulation
Motor 2

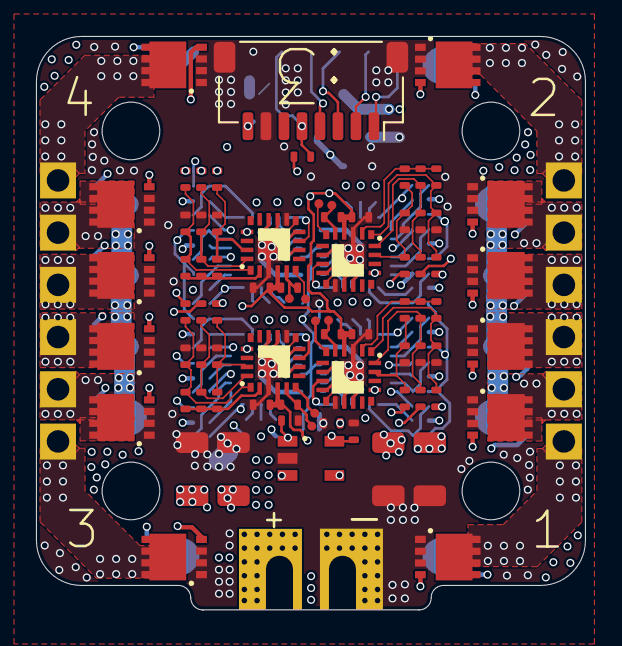
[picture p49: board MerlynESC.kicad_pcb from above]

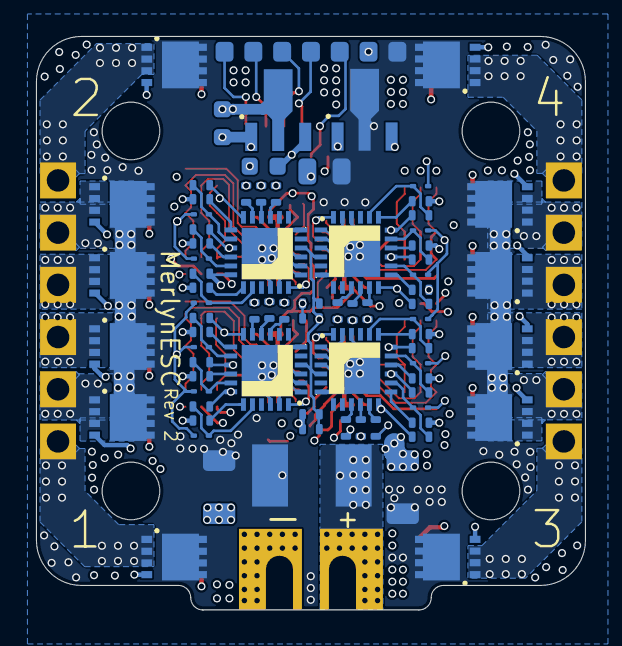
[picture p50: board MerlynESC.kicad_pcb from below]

Board: 6 copper layers, 30.5 x 31.9 mm, 159 parts (76 on the bottom side), 131 nets.

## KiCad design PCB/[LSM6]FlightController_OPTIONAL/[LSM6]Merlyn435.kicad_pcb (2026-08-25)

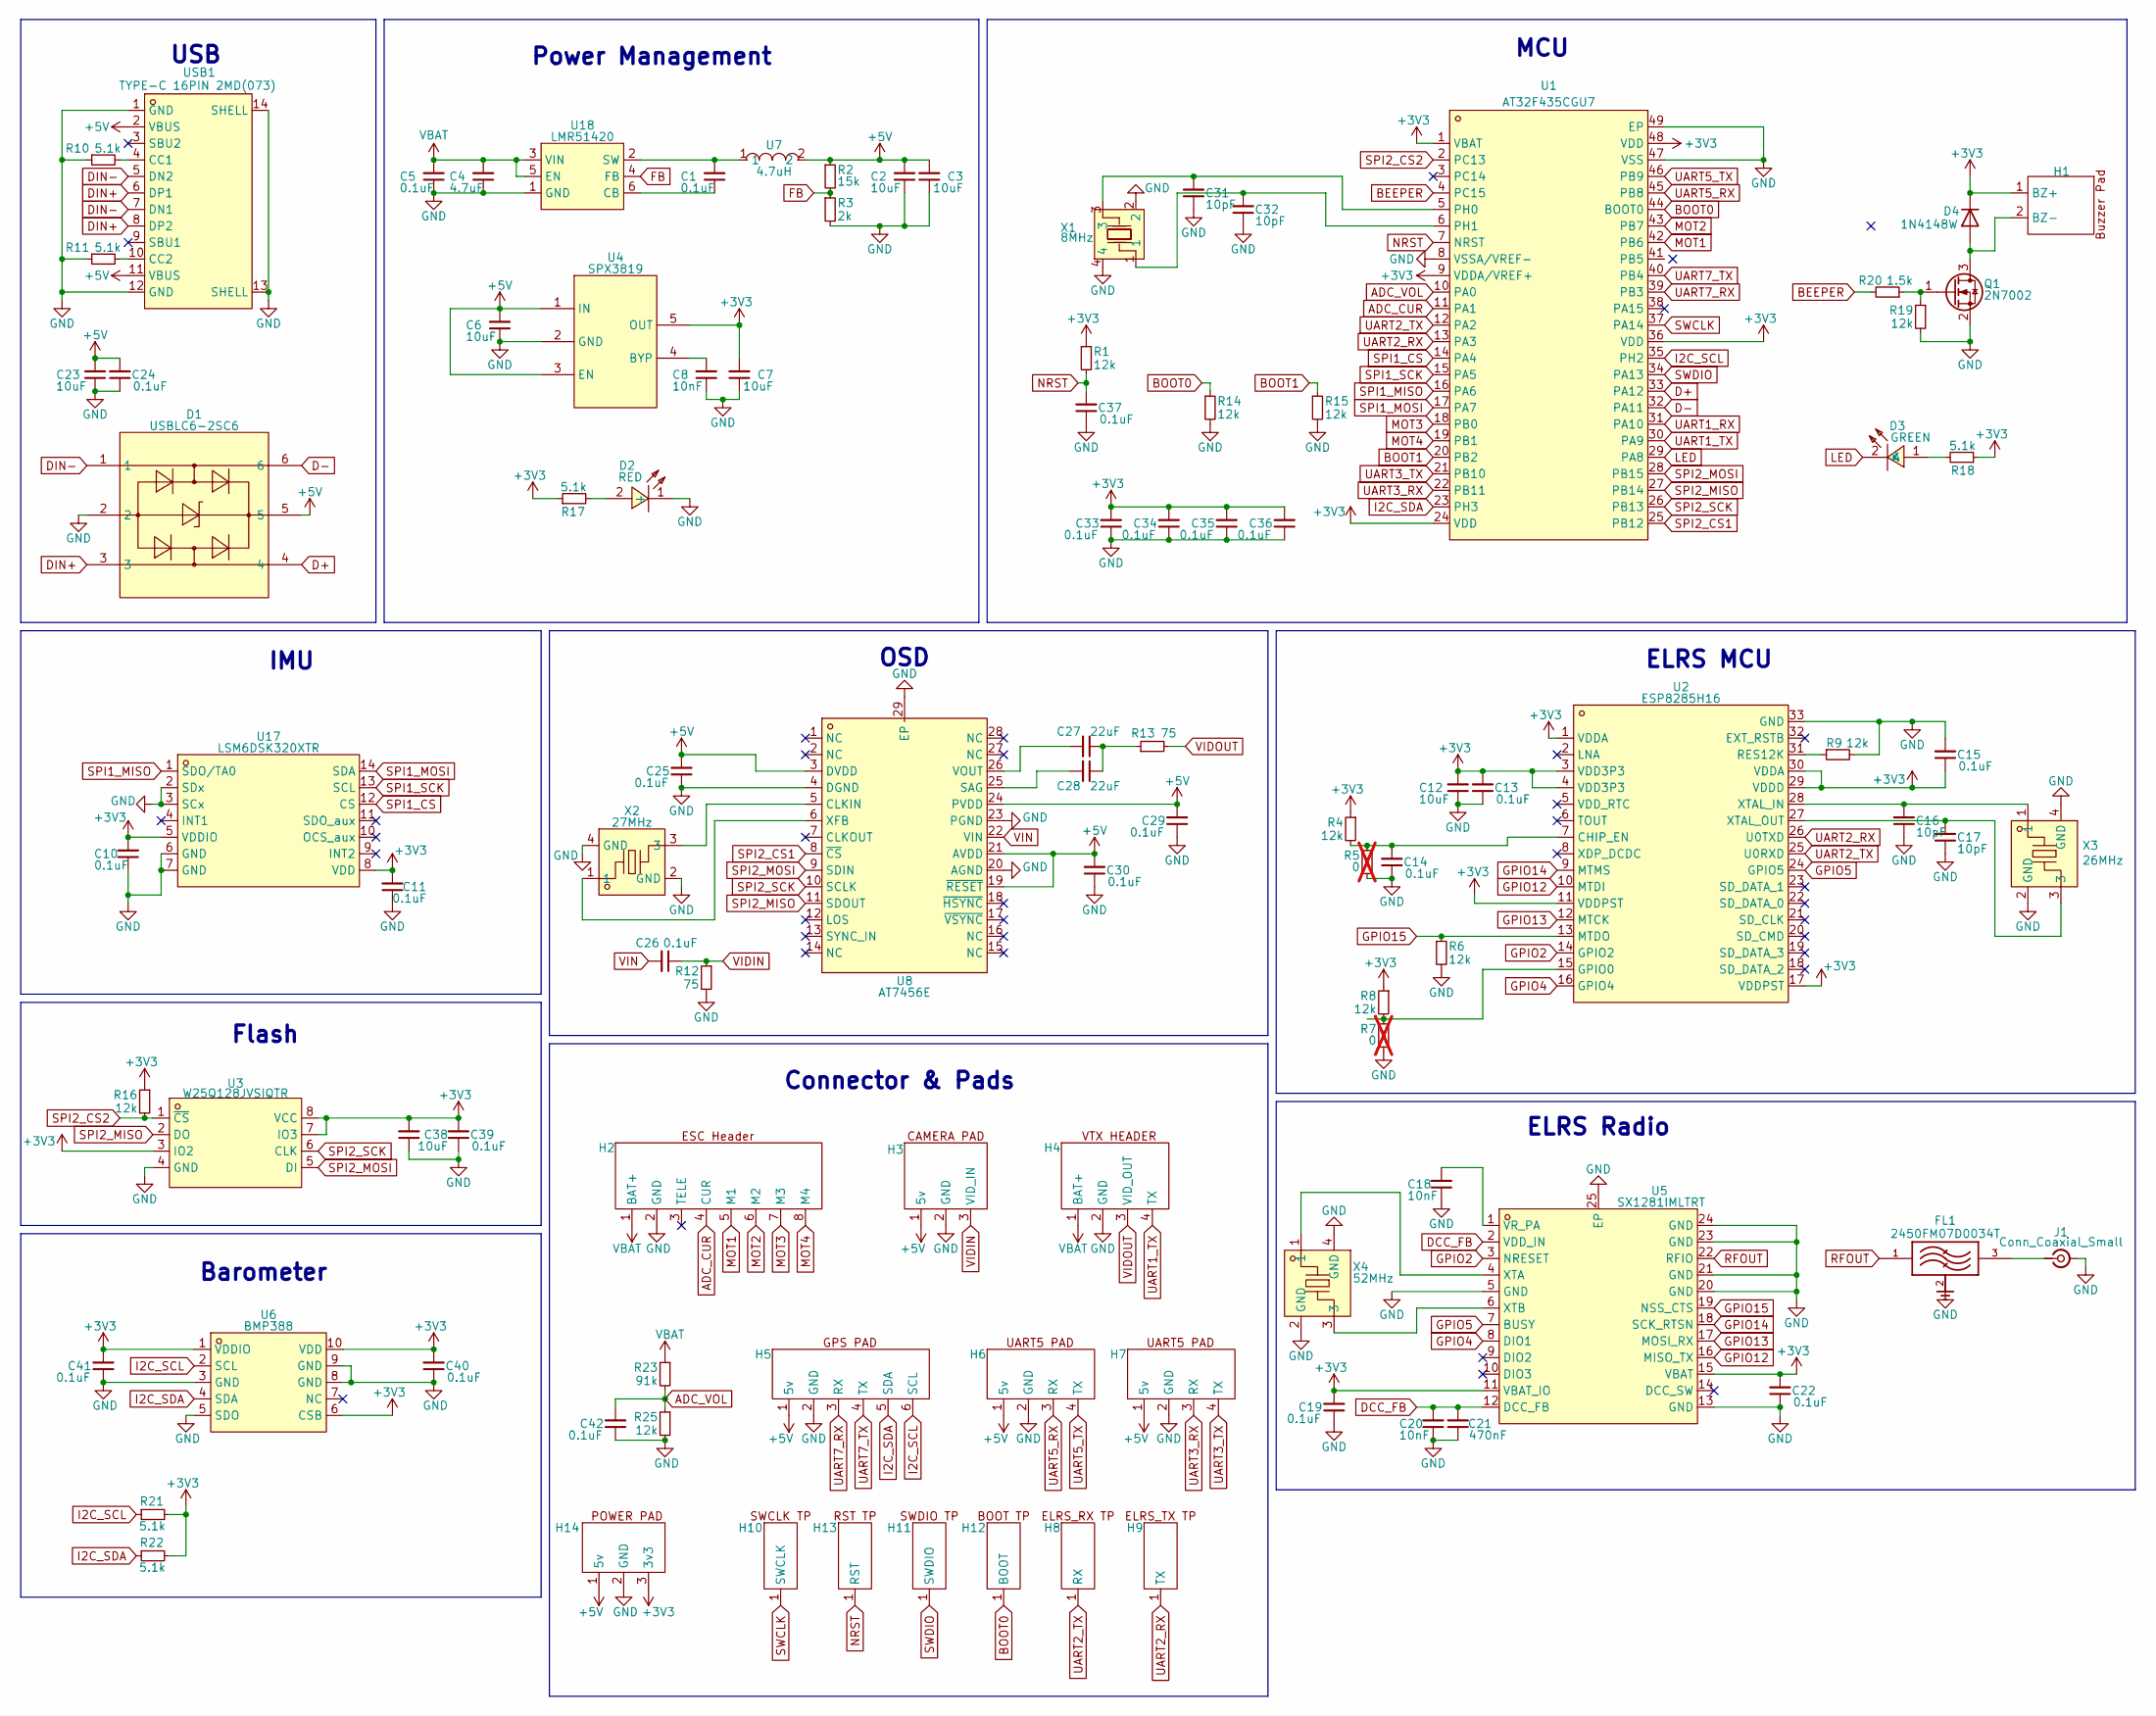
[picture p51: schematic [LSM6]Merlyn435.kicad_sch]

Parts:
C1, C5, C10, C11, C13, C14, C15, C19, C22, C24, C25, C26, C29, C30, C33, C34, C35, C36, C37, C39, C40, C41, C42: 0.1uF; C_0402_1005Metric; LCSC Part C307331
C2, C3, C6, C7: 10uF; C_0603_1608Metric; LCSC Part C96446
C4: 4.7uF; C_1206_3216Metric; LCSC Part C29823
C8, C18, C20: 10nF; C_0402_1005Metric; LCSC Part C15195
C12, C23, C38: 10uF; C_0402_1005Metric; LCSC Part C15525
C16, C17, C31, C32: 10pF; C_0402_1005Metric; LCSC Part C32949
C21: 470nF; C_0402_1005Metric; LCSC Part C47339
C27, C28: 22uF; C_0805_2012Metric; LCSC Part C45783
D1: USBLC6-2SC6; SOT-23-6_L2.9-W1.6-P0.95-LS2.8-BL; MPN USBLC6-2SC6; LCSC Part C7519
D2: RED; LED0805-RD; MPN NCD0805R1; LCSC Part C84256
D3: GREEN; LED0805-R-RD; MPN KT-0805G; LCSC Part C2297
D4: 1N4148W; D_SOD-123
FL1: 2450FM07D0034T; FIL_2450FM07D0034T; PARTREV 1.2
H1: Buzzer Pad
H2: ESC Header
H3: Camera Pad
H4: VTX Pad
H5: GPS Pad
H6: UART5 PAD
H7: UART3 PAD
H8: ELRS_RX TP
H9: ELRS_TX TP
H10: SWCLK TP
H11: SWDIO TP
H12: SWD_BOOT TP
H13: SWD_RST TP
H14: Power Pad
J1: Conn_Coaxial_Small; UFL
Q1: 2N7002; SOT-23
R1, R4, R6, R8, R9, R14, R15, R16, R19, R25: 12k; R_0402_1005Metric; LCSC Part C25752
R2: 15k; R_0402_1005Metric; LCSC Part C25756
R3: 2k; R_0402_1005Metric; LCSC Part C4109
R5, R7: 0; R_0402_1005Metric; not fitted
R10, R11, R17, R18, R21, R22: 5.1k; R_0402_1005Metric; LCSC Part C25905
R12, R13: 75; R_0402_1005Metric; LCSC Part C25133
R20: 1.5k; R_0402_1005Metric; LCSC Part C25867
R23: 91k; R_0603_1608Metric; LCSC Part C23265
U1: AT32F435CGU7; QFN-48_L6.0-W6.0-P0.40-TL-EP3.2; MPN AT32F435CGU7; LCSC Part C5178937
U2: ESP8285H16; QFN-32_L5.0-W5.0-P0.50-TL-EP3.7; MPN ESP8285H16; LCSC Part C967019
U3: W25Q128JVSIQTR; SOIC-8_L5.3-W5.3-P1.27-LS8.0-BL; MPN W25Q128JVSIQ; LCSC Part C97521
U4: SPX3819; SOT-23-5_L3.0-W1.7-P0.95-LS2.8-BL; MPN SPX3819M5-L-3-3/TR; LCSC Part C9055
U5: SX1281IMLTRT; QFN-24_L4.0-W4.0-P0.50-TL-EP2.6; MPN SX1281IMLTRT; LCSC Part C2151551
U6: BMP388; LGA-10_L2.0-W2.0-P0.50-BL; MPN BMP388(TOKMAS); LCSC Part C54582187
U7: 4.7uH; IND-SMD_L4.4-W4.2; MPN APH0420T4R7M; LCSC Part C5349668
U8: AT7456E; TSSOP-28_L9.7-W4.4-P0.65-LS6.4-BL-EP-2; MPN AT7456E; LCSC Part C82351
U17: LSM6DSK320XTR; LGA-14_L3.0-W2.5-P0.50-TL; MPN LSM6DSK320XTR; LCSC Part C53025794
U18: LMR51420; SOT-23-6_L2.9-W1.6-P0.95-LS2.9-BL; MPN LMR51420YDDCR; LCSC Part C5383002
USB1: TYPE-C 16PIN 2MD(073); USB-TYPE-C-SMD_TYPE-C-16P-QTWT; LCSC Part C5187472
X1: 8MHz; CRYSTAL-SMD_4P-L3.2-W2.5-BL; MPN TAXM8M4RDBCCT2T; LCSC Part C400090
X2: 27MHz; CRYSTAL-SMD_4P-L2.0-W1.6-BL; MPN 7D027000I01; LCSC Part C648950
X3: 26MHz; CRYSTAL-SMD_4P-L2.0-W1.6-BL; MPN XL7EL89CMI-111YLC-26M; LCSC Part C19272774
X4: 52MHz; CRYSTAL-SMD_4P-L2.0-W1.6-BL; MPN XC21M4-52.000-F10NNHPL; LCSC Part C3034316

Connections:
+3V3: C7.2, C10.2, C11.2, C12.2, C13.2, C15.1, C19.2, C22.2, C33.2, C34.2, C35.2, C36.2, C38.2, C39.2, C40.2, C41.2, D4.1 (K), H1.1 (BZ+), H14.3 (3v3), R1.1, R4.1, R8.1, R16.1, R17.1, R18.1, R21.2, R22.2, U1.1 (VBAT), U1.9 (VDDA/VREF+), U1.24 (VDD), U1.36 (VDD), U1.48 (VDD), U2.1 (VDDA), U2.3 (VDD3P3), U2.4 (VDD3P3), U2.11 (VDDPST), U2.17 (VDDPST), U2.29 (VDDD), U2.30 (VDDA), U3.3 (IO2), U3.7 (IO3), U3.8 (VCC), U4.5 (OUT), U5.11 (VBAT_IO), U5.15 (VBAT), U6.1 (VDDIO), U6.6 (CSB), U6.10 (VDD), U17.5 (VDDIO), U17.8 (VDD)
+5V: C2.2, C3.2, C6.2, C23.2, C24.2, C25.2, C29.2, C30.2, D1.5, H3.1 (5v), H5.1 (5v), H6.1 (5v), H7.1 (5v), H14.1 (5v), R2.1, U4.1 (IN), U4.3 (EN), U7.2, U8.3 (DVDD), U8.19 (~RESET), U8.21 (AVDD), U8.24 (PVDD), USB1.2 (VBUS), USB1.11 (VBUS)
ADC_CUR: H2.4 (CUR), U1.11 (PA1)
ADC_VOL: C42.2, R23.2, R25.1, U1.10 (PA0)
BEEPER: R20.2, U1.4 (PC15)
BOOT0: H12.1 (BOOT), R14.1, U1.44 (BOOT0)
BOOT1: R15.1, U1.20 (PB2)
D+: D1.4, U1.33 (PA12)
D-: D1.6, U1.32 (PA11)
DCC_FB: C20.2, C21.2, U5.2 (VDD_IN), U5.12 (DCC_FB)
DIN+: D1.3, USB1.6 (DP1), USB1.8 (DP2)
DIN-: D1.1, USB1.5 (DN2), USB1.7 (DN1)
FB: R2.2, R3.1, U18.4 (FB)
GND: C2.1, C3.1, C4.1, C5.1, C6.1, C7.1, C8.1, C10.1, C11.1, C12.1, C13.1, C14.1, C15.2, C16.1, C17.1, C18.1, C19.1, C20.1, C21.1, C22.1, C23.1, C24.1, C25.1, C29.1, C30.1, C31.1, C32.1, C33.1, C34.1, C35.1, C36.1, C37.1, C38.1, C39.1, C40.1, C41.1, C42.1, D1.2, D2.1 (-), FL1.2, FL1.4, H2.2 (GND), H3.2 (GND), H4.2 (GND), H5.2 (GND), H6.2 (GND), H7.2 (GND), H14.2 (GND), J1.2 (Ext), Q1.2 (S), R3.2, R5.2, R6.2, R7.2, R9.2, R10.1, R11.1, R12.2, R14.2, R15.2, R19.2, R25.2, U1.8 (VSSA/VREF-), U1.47 (VSS), U1.49 (EP), U2.33 (GND), U3.4 (GND), U4.2 (GND), U5.5 (GND), U5.13 (GND), U5.20 (GND), U5.21 (GND), U5.23 (GND), U5.24 (GND), U5.25 (EP), U6.3 (GND), U6.5 (SDO), U6.8 (GND), U6.9 (GND), U8.4 (DGND), U8.20 (AGND), U8.23 (PGND), U8.29 (EP), U17.2 (SDx), U17.3 (SCx), U17.6 (GND), U17.7 (GND), U18.1 (GND), USB1.1 (GND), USB1.12 (GND), USB1.13 (SHELL), USB1.14 (SHELL), X1.2, X1.4, X2.2 (GND), X2.4 (GND), X3.2 (GND), X3.4 (GND), X4.2 (GND), X4.4 (GND)
GPIO2: U2.14 (GPIO2), U5.3 (NRESET)
GPIO4: U2.16 (GPIO4), U5.8 (DIO1)
GPIO5: U2.24 (GPIO5), U5.7 (BUSY)
GPIO12: U2.10 (MTDI), U5.16 (MISO_TX)
GPIO13: U2.12 (MTCK), U5.17 (MOSI_RX)
GPIO14: U2.9 (MTMS), U5.18 (SCK_RTSN)
GPIO15: R6.1, U2.13 (MTDO), U5.19 (NSS_CTS)
I2C_SCL: H5.6 (SCL), R21.1, U1.35 (PH2), U6.2 (SCL)
I2C_SDA: H5.5 (SDA), R22.1, U1.23 (PH3), U6.4 (SDA)
LED: D3.2 (K), U1.29 (PA8)
MOT1: H2.5 (M1), U1.42 (PB6)
MOT2: H2.6 (M2), U1.43 (PB7)
MOT3: H2.7 (M3), U1.18 (PB0)
MOT4: H2.8 (M4), U1.19 (PB1)
NRST: C37.2, H13.1 (RST), R1.2, U1.7 (NRST)
unnamed: C27.1, C28.1, R13.1
unnamed: D2.2 (+), R17.2
unnamed: D3.1 (A), R18.2
unnamed: D4.2 (A), H1.2 (BZ-), Q1.3 (D)
unnamed: FL1.3, J1.1 (In)
unnamed: Q1.1 (G), R19.1, R20.1
unnamed: C31.2, U1.5 (PH0), X1.3
unnamed: C32.2, U1.6 (PH1), X1.1
unnamed: C14.2, R4.2, R5.1, U2.7 (CHIP_EN)
unnamed: R7.1, R8.2, U2.15 (GPIO0)
unnamed: R9.1, U2.31 (RES12K)
unnamed: C16.2, U2.28 (XTAL_IN), X3.1
unnamed: C17.2, U2.27 (XTAL_OUT), X3.3
unnamed: C8.2, U4.4 (BYP)
unnamed: C18.2, U5.1 (VR_PA)
unnamed: U5.4 (XTA), X4.1
unnamed: U5.6 (XTB), X4.3
unnamed: U8.5 (CLKIN), X2.3
unnamed: C28.2, U8.25 (SAG)
unnamed: C27.2, U8.26 (VOUT)
unnamed: U8.6 (XFB), X2.1
unnamed: C1.1, U18.6 (CB)
unnamed: C1.2, U7.1, U18.2 (SW)
unnamed: R10.2, USB1.4 (CC1)
unnamed: R11.2, USB1.10 (CC2)
RFOUT: FL1.1, U5.22 (RFIO)
SPI1_CS: U1.14 (PA4), U17.12 (CS)
SPI1_MISO: U1.16 (PA6), U17.1 (SDO/TA0)
SPI1_MOSI: U1.17 (PA7), U17.14 (SDA)
SPI1_SCK: U1.15 (PA5), U17.13 (SCL)
SPI2_CS1: U1.25 (PB12), U8.8 (~CS)
SPI2_CS2: R16.2, U1.2 (PC13), U3.1 (~CS)
SPI2_MISO: U1.27 (PB14), U3.2 (DO), U8.11 (SDOUT)
SPI2_MOSI: U1.28 (PB15), U3.5 (DI), U8.9 (SDIN)
SPI2_SCK: U1.26 (PB13), U3.6 (CLK), U8.10 (SCLK)
SWCLK: H10.1 (SWCLK), U1.37 (PA14)
SWDIO: H11.1 (SWDIO), U1.34 (PA13)
UART1_RX: U1.31 (PA10)
UART1_TX: H4.4 (TX), U1.30 (PA9)
UART2_RX: H9.1 (TX), U1.13 (PA3), U2.26 (U0TXD)
UART2_TX: H8.1 (RX), U1.12 (PA2), U2.25 (U0RXD)
UART3_RX: H7.3 (RX), U1.22 (PB11)
UART3_TX: H7.4 (TX), U1.21 (PB10)
UART5_RX: H6.3 (RX), U1.45 (PB8)
UART5_TX: H6.4 (TX), U1.46 (PB9)
UART7_RX: H5.3 (RX), U1.39 (PB3)
UART7_TX: H5.4 (TX), U1.40 (PB4)
VBAT: C4.2, C5.2, H2.1 (BAT+), H4.1 (BAT+), R23.1, U18.3 (VIN), U18.5 (EN)
VIDIN: C26.1, H3.3 (VID_IN), R12.1
VIDOUT: H4.3 (VID_OUT), R13.2
VIN: C26.2, U8.22 (VIN)

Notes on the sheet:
Barometer
USB
Power Management
ELRS Radio
Connector & Pads
MCU
ELRS MCU
OSD
IMU
Flash

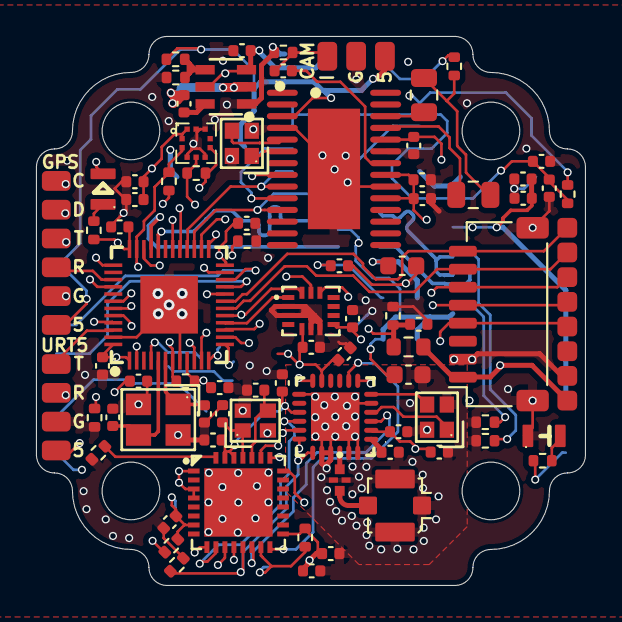
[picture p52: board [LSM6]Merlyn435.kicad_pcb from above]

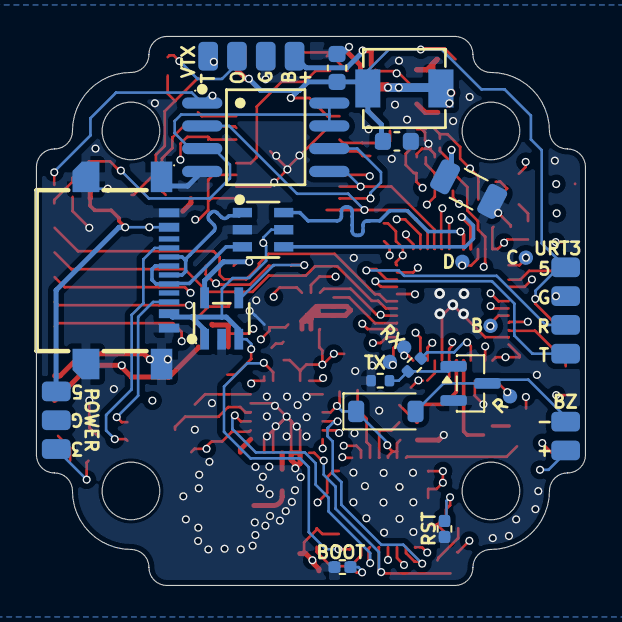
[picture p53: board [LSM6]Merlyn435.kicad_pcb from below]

Board: 4 copper layers, 30.5 x 30.5 mm, 101 parts (24 on the bottom side), 79 nets.

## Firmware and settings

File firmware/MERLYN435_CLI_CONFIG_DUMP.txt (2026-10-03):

# 
# dump all

# version
# Betaflight / AT32F435G (A435G) 2026.6.1 Aug 25 2026 / 17:41:18 (norevision) MSP API: 1.48
# config rev: 749fff1

# start the command batch
batch start

board_name MERLYN435
manufacturer_id ANSON
mcu_id 2099dcad0da500000d219702
signature 

# name: -

# resources
resource BEEPER 1 C15
resource MOTOR 1 B06
resource MOTOR 2 B07
resource MOTOR 3 B00
resource MOTOR 4 B01
resource MOTOR 5 NONE
resource MOTOR 6 NONE
resource MOTOR 7 NONE
resource MOTOR 8 NONE
resource SERVO 1 NONE
resource SERVO 2 NONE
resource SERVO 3 NONE
resource SERVO 4 NONE
resource SERVO 5 NONE
resource SERVO 6 NONE
resource SERVO 7 NONE
resource SERVO 8 NONE
resource SONAR_TRIGGER 1 NONE
resource SONAR_ECHO 1 NONE
resource LED_STRIP 1 NONE
resource SERIAL_TX 1 A09
resource SERIAL_TX 2 A02
resource SERIAL_TX 3 B10
resource SERIAL_TX 4 NONE
resource SERIAL_TX 5 B09
resource SERIAL_TX 6 NONE
resource SERIAL_TX 7 B04
resource SERIAL_TX 8 NONE
resource SERIAL_RX 1 A10
resource SERIAL_RX 2 A03
resource SERIAL_RX 3 B11
resource SERIAL_RX 4 NONE
resource SERIAL_RX 5 B08
resource SERIAL_RX 6 NONE
resource SERIAL_RX 7 B03
resource SERIAL_RX 8 NONE
resource I2C_SCL 1 NONE
resource I2C_SCL 2 H02
resource I2C_SCL 3 NONE
resource I2C_SCL 4 NONE
resource I2C_SDA 1 NONE
resource I2C_SDA 2 H03
resource I2C_SDA 3 NONE
resource I2C_SDA 4 NONE
resource LED 1 A08
resource LED 2 NONE
resource LED 3 NONE
resource RX_BIND 1 NONE
resource RX_BIND_PLUG 1 NONE
resource SPI_SCK 1 A05
resource SPI_SCK 2 B13
resource SPI_SCK 3 NONE
resource SPI_SCK 4 NONE
resource SPI_SDI 1 A06
resource SPI_SDI 2 B14
resource SPI_SDI 3 NONE
resource SPI_SDI 4 NONE
resource SPI_SDO 1 A07
resource SPI_SDO 2 B15
resource SPI_SDO 3 NONE
resource SPI_SDO 4 NONE
resource ESCSERIAL 1 NONE
resource ADC_BATT 1 A00
resource ADC_RSSI 1 NONE
resource ADC_CURR 1 A01
resource ADC_EXT 1 NONE
resource BARO_CS 1 NONE
resource BARO_EOC 1 NONE
resource BARO_XCLR 1 NONE
resource PINIO 1 NONE
resource PINIO 2 NONE
resource PINIO 3 NONE
resource PINIO 4 NONE
resource USB_MSC_PIN 1 NONE
resource FLASH_CS 1 C13
resource OSD_CS 1 B12
resource GYRO_EXTI 1 NONE
resource GYRO_CS 1 A04
resource USB_DETECT 1 NONE
resource VTX_POWER 1 NONE
resource VTX_CS 1 NONE
resource VTX_DATA 1 NONE
resource VTX_CLK 1 NONE
resource PULLUP 1 NONE
resource PULLUP 2 NONE
resource PULLUP 3 NONE
resource PULLUP 4 NONE
resource PULLDOWN 1 NONE
resource PULLDOWN 2 NONE
resource PULLDOWN 3 NONE
resource PULLDOWN 4 NONE

# timer
timer B06 AF2
# pin B06: TIM4 CH1 (AF2)
timer B07 AF2
# pin B07: TIM4 CH2 (AF2)
timer B00 AF2
# pin B00: TIM3 CH3 (AF2)
timer B01 AF2
# pin B01: TIM3 CH4 (AF2)

# dma
dma SPI_SDO 1 NONE
dma SPI_SDO 2 NONE
dma SPI_SDO 3 NONE
dma SPI_SDO 4 NONE
dma SPI_SDI 1 NONE
dma SPI_SDI 2 NONE
dma SPI_SDI 3 NONE
dma SPI_SDI 4 NONE
dma SPI_TX 1 NONE
dma SPI_TX 2 NONE
dma SPI_TX 3 NONE
dma SPI_TX 4 NONE
dma SPI_RX 1 NONE
dma SPI_RX 2 NONE
dma SPI_RX 3 NONE
dma SPI_RX 4 NONE
dma ADC 1 11
# ADC 1: DMA2 Channel 5 Request 5
dma ADC 2 NONE
dma ADC 3 NONE
dma UART_TX 1 NONE
dma UART_TX 2 NONE
dma UART_TX 3 NONE
dma UART_TX 4 NONE
dma UART_TX 5 NONE
dma UART_TX 6 NONE
dma UART_TX 7 NONE
dma UART_TX 8 NONE
dma UART_RX 1 NONE
dma UART_RX 2 NONE
dma UART_RX 3 NONE
dma UART_RX 4 NONE
dma UART_RX 5 NONE
dma UART_RX 6 NONE
dma UART_RX 7 NONE
dma UART_RX 8 NONE
dma pin B06 0
# pin B06: DMA1 Channel 1 Request 67
dma pin B07 1
# pin B07: DMA1 Channel 2 Request 68
dma pin B00 2
# pin B00: DMA1 Channel 3 Request 63
dma pin B01 3
# pin B01: DMA1 Channel 4 Request 64

# feature
feature -RX_PPM
feature -RX_UDP
feature -INFLIGHT_ACC_CAL
feature -RX_SERIAL
feature -MOTOR_STOP
feature -SERVO_TILT
feature -SOFTSERIAL
feature -GPS
feature -OPTICALFLOW
feature -RANGEFINDER
feature -TELEMETRY
feature -3D
feature -RX_PARALLEL_PWM
feature -RX_MSP
feature -RSSI_ADC
feature -LED_STRIP
feature -DISPLAY
feature -OSD
feature -CHANNEL_FORWARDING
feature -TRANSPONDER
feature -AIRMODE
feature -RX_SPI
feature -ESC_SENSOR
feature -ANTI_GRAVITY
feature RX_SERIAL
feature GPS
feature TELEMETRY
feature LED_STRIP
feature OSD
feature AIRMODE
feature ANTI_GRAVITY

# serial
serial VCP 1 115200 57600 0 115200
serial UART1 2048 115200 57600 0 115200
serial UART2 64 115200 57600 0 115200
serial UART3 0 115200 57600 0 115200
serial UART5 0 115200 57600 0 115200
serial UART7 2 115200 57600 0 115200

# mixer
mixer QUADX

mmix reset


# servo
servo 0 1000 2000 1500 100 -1
servo 1 1000 2000 1500 100 -1
servo 2 1000 2000 1500 100 -1
servo 3 1000 2000 1500 100 -1
servo 4 1000 2000 1500 100 -1
servo 5 1000 2000 1500 100 -1
servo 6 1000 2000 1500 100 -1
servo 7 1000 2000 1500 100 -1

# servo mixer
smix reset


# beeper
beeper GYRO_CALIBRATED
beeper RX_LOST
beeper RX_LOST_LANDING
beeper DISARMING
beeper ARMING
beeper ARMING_GPS_FIX
beeper ARMING_GPS_NO_FIX
beeper BAT_CRIT_LOW
beeper BAT_LOW
beeper GPS_STATUS
beeper RX_SET
beeper ACC_CALIBRATION
beeper ACC_CALIBRATION_FAIL
beeper READY_BEEP
beeper MULTI_BEEPS
beeper DISARM_REPEAT
beeper ARMED
beeper SYSTEM_INIT
beeper ON_USB
beeper BLACKBOX_ERASE
beeper CRASHFLIP
beeper CAM_CONNECTION_OPEN
beeper CAM_CONNECTION_CLOSE

# beacon
beacon -RX_LOST
beacon -RX_SET

# map
map AETR1234

# led
led 0 0,0::C:0
led 1 0,0::C:0
led 2 0,0::C:0
led 3 0,0::C:0
led 4 0,0::C:0
led 5 0,0::C:0
led 6 0,0::C:0
led 7 0,0::C:0
led 8 0,0::C:0
led 9 0,0::C:0
led 10 0,0::C:0
led 11 0,0::C:0
led 12 0,0::C:0
led 13 0,0::C:0
led 14 0,0::C:0
led 15 0,0::C:0
led 16 0,0::C:0
led 17 0,0::C:0
led 18 0,0::C:0
led 19 0,0::C:0
led 20 0,0::C:0
led 21 0,0::C:0
led 22 0,0::C:0
led 23 0,0::C:0
led 24 0,0::C:0
led 25 0,0::C:0
led 26 0,0::C:0
led 27 0,0::C:0
led 28 0,0::C:0
led 29 0,0::C:0
led 30 0,0::C:0
led 31 0,0::C:0

# color
color 0 0,0,0
color 1 0,255,255
color 2 0,0,255
color 3 15,0,255
color 4 50,0,255
color 5 100,0,255
color 6 115,0,255
color 7 125,0,255
color 8 180,0,255
color 9 210,0,255
color 10 240,0,255
color 11 270,0,255
color 12 300,0,255
color 13 330,0,255
color 14 0,0,0
color 15 0,0,0

# mode_color
mode_color 0 0 1
mode_color 0 1 11
mode_color 0 2 2
mode_color 0 3 13
mode_color 0 4 10
mode_color 0 5 3
mode_color 1 0 5
mode_color 1 1 11
mode_color 1 2 3
mode_color 1 3 13
mode_color 1 4 10
mode_color 1 5 3
mode_color 2 0 10
mode_color 2 1 11
mode_color 2 2 4
mode_color 2 3 13
mode_color 2 4 10
mode_color 2 5 3
mode_color 3 0 8
mode_color 3 1 11
mode_color 3 2 4
mode_color 3 3 13
mode_color 3 4 10
mode_color 3 5 3
mode_color 4 0 7
mode_color 4 1 11
mode_color 4 2 3
mode_color 4 3 13
mode_color 4 4 10
mode_color 4 5 3
mode_color 5 0 0
mode_color 5 1 0
mode_color 5 2 0
mode_color 5 3 0
mode_color 5 4 0
mode_color 5 5 0
mode_color 6 0 6
mode_color 6 1 10
mode_color 6 2 1
mode_color 6 3 0
mode_color 6 4 0
mode_color 6 5 2
mode_color 6 6 3
mode_color 6 7 6
mode_color 6 8 0
mode_color 6 9 0
mode_color 6 10 0
mode_color 7 0 3

# aux
aux 0 0 0 1975 2025 0 0
aux 1 1 1 1475 2025 0 0
aux 2 46 2 1975 2025 0 0
aux 3 13 5 1975 2025 0 0
aux 4 35 3 1975 2025 0 0
aux 5 0 0 900 900 0 0
aux 6 0 0 900 900 0 0
aux 7 0 0 900 900 0 0
aux 8 0 0 900 900 0 0
aux 9 0 0 900 900 0 0
aux 10 0 0 900 900 0 0
aux 11 0 0 900 900 0 0
aux 12 0 0 900 900 0 0
aux 13 0 0 900 900 0 0
aux 14 0 0 900 900 0 0
aux 15 0 0 900 900 0 0
aux 16 0 0 900 900 0 0
aux 17 0 0 900 900 0 0
aux 18 0 0 900 900 0 0
aux 19 0 0 900 900 0 0

# adjrange
adjrange 0 0 1 975 2025 12 1 0 0
adjrange 1 0 0 900 900 0 0 0 0
adjrange 2 0 0 900 900 0 0 0 0
adjrange 3 0 0 900 900 0 0 0 0
adjrange 4 0 0 900 900 0 0 0 0
adjrange 5 0 0 900 900 0 0 0 0
adjrange 6 0 0 900 900 0 0 0 0
adjrange 7 0 0 900 900 0 0 0 0
adjrange 8 0 0 900 900 0 0 0 0
adjrange 9 0 0 900 900 0 0 0 0
adjrange 10 0 0 900 900 0 0 0 0
adjrange 11 0 0 900 900 0 0 0 0
adjrange 12 0 0 900 900 0 0 0 0
adjrange 13 0 0 900 900 0 0 0 0
adjrange 14 0 0 900 900 0 0 0 0
adjrange 15 0 0 900 900 0 0 0 0
adjrange 16 0 0 900 900 0 0 0 0
adjrange 17 0 0 900 900 0 0 0 0
adjrange 18 0 0 900 900 0 0 0 0
adjrange 19 0 0 900 900 0 0 0 0
adjrange 20 0 0 900 900 0 0 0 0
adjrange 21 0 0 900 900 0 0 0 0
adjrange 22 0 0 900 900 0 0 0 0
adjrange 23 0 0 900 900 0 0 0 0
adjrange 24 0 0 900 900 0 0 0 0
adjrange 25 0 0 900 900 0 0 0 0
adjrange 26 0 0 900 900 0 0 0 0
adjrange 27 0 0 900 900 0 0 0 0
adjrange 28 0 0 900 900 0 0 0 0
adjrange 29 0 0 900 900 0 0 0 0

# rxrange
rxrange 0 1000 2000
rxrange 1 1000 2000
rxrange 2 1000 2000
rxrange 3 1000 2000

# vtxtable
vtxtable bands 5
vtxtable channels 8
vtxtable band 1 BOSCAM_A A FACTORY 5865 5845 5825 5805 5785 5765 5745 5725
vtxtable band 2 BOSCAM_B B FACTORY 5733 5752 5771 5790 5809 5828 5847 5866
vtxtable band 3 BOSCAM_E E FACTORY 5705 5685 5665 5645 5885 5905 5925 5945
vtxtable band 4 FATSHARK F FACTORY 5740 5760 5780 5800 5820 5840 5860 5880
vtxtable band 5 RACEBAND R FACTORY 5658 5695 5732 5769 5806 5843 5880 5917
vtxtable powerlevels 5
vtxtable powervalues 14 20 23 26 30
vtxtable powerlabels 25 100 200 400 1W
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

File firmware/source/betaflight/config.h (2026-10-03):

/*
 * This file is part of Betaflight.
 *
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
 * See the GNU General Public License for more details.
 *
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
 * If not, see <http://www.gnu.org/licenses/>.
 */

#pragma once

#define FC_TARGET_MCU        AT32F435G

#define BOARD_NAME           MERLYN435
#define MANUFACTURER_ID      ANSON

// ---- CLOCK ----
#define SYSTEM_HSE_MHZ       8

// ---- INTERNAL COMPONENTS ----
#define USE_ACC
#define USE_GYRO

// LGA-14 footprint IMUs
#define USE_ACCGYRO_LSM6DSK320X
#define USE_ACCGYRO_ICM42688P
#define USE_ACCGYRO_ICM42605
#define USE_ACCGYRO_LSM6DSV16X
#define USE_ACCGYRO_LSM6DSO
#define USE_ACCGYRO_BMI270
#define USE_ACCGYRO_BMI160

#define USE_BARO
#define USE_BARO_DPS310
#define USE_BARO_SPA06_003

#define USE_MAX7456

#define USE_FLASH
#define USE_FLASH_W25Q128FV

// ---- PIN MAPPING ----
#define LED0_PIN             PA8
#define BEEPER_PIN           PC15
#define BEEPER_INVERTED

// ---- ADC ----
#define USE_ADC
#define ADC_VBAT_PIN         PA0
#define ADC_CURR_PIN         PA1
#define ADC_INSTANCE         ADC1
#define ADC1_DMA_OPT         11

// ---- MOTORS ----
#define MOTOR1_PIN           PB6
#define MOTOR2_PIN           PB7
#define MOTOR3_PIN           PB0
#define MOTOR4_PIN           PB1

// ---- UARTS ----
#define UART1_TX_PIN         PA9
#define UART1_RX_PIN         PA10
#define UART2_TX_PIN         PA2
#define UART2_RX_PIN         PA3
#define UART3_TX_PIN         PB10
#define UART3_RX_PIN         PB11
#define UART5_TX_PIN         PB9
#define UART5_RX_PIN         PB8
#define UART7_TX_PIN         PB4
#define UART7_RX_PIN         PB3

// ---- I2C (External + BMP388) ----
#define I2C2_SCL_PIN         PH2
#define I2C2_SDA_PIN         PH3

// ---- SPI1 (IMU) ----
#define SPI1_SCK_PIN         PA5
#define SPI1_SDI_PIN         PA6
#define SPI1_SDO_PIN         PA7

// ---- SPI2 (Flash & OSD) ----
#define SPI2_SCK_PIN         PB13
#define SPI2_SDI_PIN         PB14
#define SPI2_SDO_PIN         PB15

// ---- CHIP SELECTS ----
#define GYRO_1_CS_PIN        PA4
#define MAX7456_SPI_CS_PIN   PB12
#define FLASH_CS_PIN         PC13

// ---- HARDWARE INSTANCES ----
#define GYRO_1_SPI_INSTANCE  SPI1
#define FLASH_SPI_INSTANCE   SPI2
#define MAX7456_SPI_INSTANCE SPI2
#define BARO_I2C_INSTANCE    I2CDEV_2
#define MAG_I2C_INSTANCE     I2CDEV_2

// ---- TIMER MAPPING ----
#define TIMER_PIN_MAPPING \
    TIMER_PIN_MAP( 0, PB6, 1,  0) \
    TIMER_PIN_MAP( 1, PB7, 1,  1) \
    TIMER_PIN_MAP( 2, PB0, 2,  2) \
    TIMER_PIN_MAP( 3, PB1, 2,  3)

// ---- DEFAULTS ----
#define DEFAULT_BLACKBOX_DEVICE         BLACKBOX_DEVICE_FLASH
#define DEFAULT_CURRENT_METER_SOURCE    CURRENT_METER_ADC
#define DEFAULT_VOLTAGE_METER_SOURCE    VOLTAGE_METER_ADC
#define DEFAULT_DSHOT_BITBANG           DSHOT_BITBANG_ON
#define DEFAULT_DSHOT_BURST             DSHOT_DMAR_AUTO
#define SERIALRX_UART                   SERIAL_PORT_USART2

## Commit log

2026-08-05 routing checkpoint
    [Merlyn.kicad_pcb, Merlyn.kicad_sch]
2026-08-09 polka dots
    [Merlyn.kicad_pcb, Merlyn.kicad_sch]
2026-08-10 completed flight controller
    [Merlyn.kicad_pcb, Merlyn.kicad_sch]
2026-08-14 added ESC
    [Merlyn.kicad_pcb, Merlyn.kicad_sch, MerlynESC.kicad_pcb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]
2026-08-14 minor esc fixes
    [MerlynESC.kicad_sch]
2026-08-24 fixed minor spelling error, formatting error, BOM error, minor specification error
    [BOM.csv]
2026-08-24 added 3 inch frame + step file + 3d source file + STLs for 3d print
    [Merlyn411Frame3inVer.f3d, Merlyn411Frame3inVer.step, gpsLock.stl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]
2026-08-24 specified PCB assembly is partial instead of complete assembly
    [BOM.csv]
2026-08-25 Added LSM6DSK320X suport
    Updated marketing material/photo to display updated IMU. Switched over from MPU6500 to new IMU, read README to lean more. Updated inav and betaflight config to support both IMU. Updated Betaflight 20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
    [BOM.csv, LSM6Merlyn435_bom.csv, LSM6Merlyn435_positions.csv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]
2026-09-04 updated cart based on LCSC updated min QTY
    [BOM.csv]
2026-09-04 added assembly instructions and updated assembled CAD model
2026-10-03 added support for more IMU and clone baro, added CLI dump
    [MERLYN435_CLI_CONFIG_DUMP.txt]
2026-10-04 ESC Rev 2. Connected gate driver VS pin to motor phase
    [MerlynESC.kicad_pcb, MerlynESC.kicad_sch, MerlynESC_bom.csv]

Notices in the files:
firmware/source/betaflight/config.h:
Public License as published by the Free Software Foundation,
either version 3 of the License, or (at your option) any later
